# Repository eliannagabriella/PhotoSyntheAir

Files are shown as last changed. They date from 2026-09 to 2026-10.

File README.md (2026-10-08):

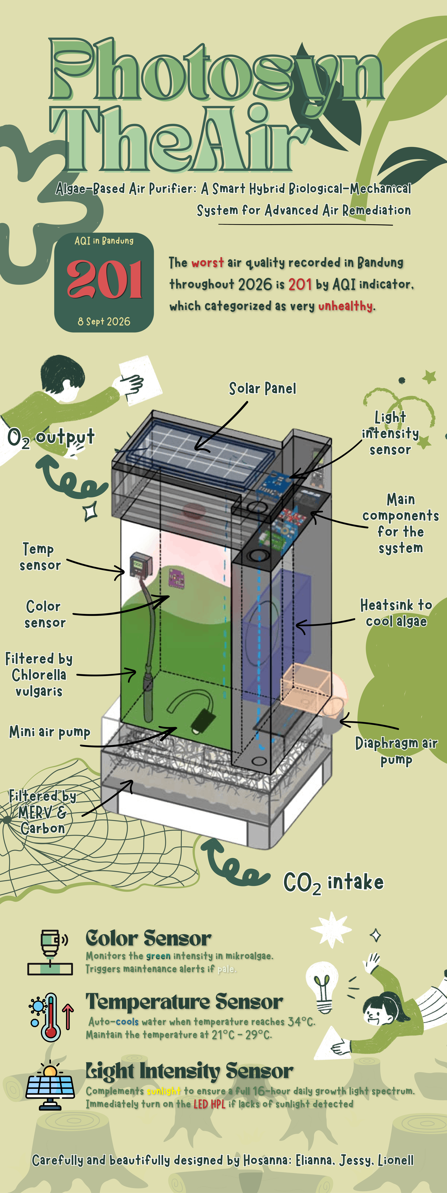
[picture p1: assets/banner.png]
Description of image


# Algae Air Purifier — ESP32-S3 firmware & wiring guide

Air path: MERV filter U25 → activated carbon (1000 iodine) → Ocypus Gamma F12 intake fan → diaphragm pump (micro-bubble diffuser) → algae chamber (mini submersible pump circulates water) → ~27% headspace releases O₂.

The ESP32-S3 doesn't touch the air path, it watches the algae (color, temperature, light) and runs the cooling loop, the grow light, and the dashboard also notifications.

## 1. Bill of materials

| Ref | Part | Where | Why |
|---|---|---|---|
| R1 | 4.7 kΩ resistor | DS18B20 DATA → 3.3V | OneWire is open-drain; without this pull-up the sensor can't pull the line high and reads garbage/-127°C. |
| R2 | 220 Ω resistor | GPIO5 → MOSFET1 gate | Limits inrush current into the gate capacitance; protects the GPIO pin. |
| R3 | 10 kΩ resistor | MOSFET1 gate → GND | Pull-down so the MOSFET is guaranteed OFF while the ESP32 is booting/resetting and the GPIO is floating. Without this, the peltier/fan can glitch on for a moment at every power-up. |
| R4 | 220 Ω resistor | GPIO6 → MOSFET2 gate | Same reason as R2, for the LED MOSFET. |
| R5 | 10 kΩ resistor | MOSFET2 gate → GND | Same reason as R3, for the LED MOSFET (keeps the grow light off during boot). |
| D1 | 1N4007 (or SS34 Schottky) | Across heatsink fan +/- | Flyback diode — the fan is a small inductive DC motor; without a return path for its collapsing field current, every OFF transition puts a voltage spike on MOSFET1's drain. |
| D2, D3, D4 | 1N4007 (optional but recommended) | Across ocypus fan, diaphragm pump, submersible pump | These are wired directly to the rail with no MOSFET, but they're still brushed/BLDC motors — a diode across each protects the 12V rail from switch-on/off spikes when the whole system powers up or a fuse/switch is toggled. |

If your TCS34725 / BH1750 breakout boards are bare chips rather than Adafruit/GY-style modules, also add two 4.7 kΩ pull-ups from SDA and SCL to 3.3V. Almost every breakout board already has these onboard, check before adding a second set, since doubled-up pull-ups just waste a little current, but confirm rather than assume.

## 2. Power architecture

```mermaid
flowchart LR
    SP[Solar panel] --> CH[2S Li-ion charger 4A]
    CH --> BATT[(2x 3.7V battery)]
    BATT --> SU[Step-up XL6019 -> 12V 5A]
    BATT --> SD[Step-down XL4015 -> 3.3V]
    GRID[State Electricity Power / grid, backup] -.-> SU

    SU --> M1[Ocypus F12 fan - always on]
    SU --> M2[Diaphragm pump - always on]
    SU --> M3[Submersible pump - always on]
    SU --> MOS1[MOSFET1 IRLB8721]
    MOS1 --> PEL[Peltier TEC-12706]
    MOS1 --> HSF[Heatsink fan]
    SU --> LM[LM2596S LED driver 12V->5V]
    LM --> MOS2[MOSFET2 IRLB8721 PWM]
    MOS2 --> LED[HPL 3W grow LED]
    LM -.5V.-> ESP[ESP32-S3 VIN]

    SD --> TCS[TCS34725]
    SD --> DS[DS18B20]
    SD --> BH[BH1750]
```

**Priority is physical, not firmware-controlled** : wire the solar panel into the charger's input, the charger's battery output into the XL6019 & XL4015 inputs, and the grid/State Electricity Company supply into the same 12V bus through a diode or manually switched backup input. That priority comes from how you wire the supplies together (e.g. a diode-OR or a physical/automatic transfer switch on the 12V bus) — it isn't something the ESP32-S3 arbitrates in software.

Tie **all grounds together** : battery/12V rail GND, 5V rail GND, 3.3V rail GND, ESP32-S3 GND, and both MOSFET sources. If the ESP32-S3 and the sensors don't share a ground reference with the loads, the MOSFET gate signal has no reliable 0V reference and behaves erratically.

Power the ESP32-S3 board itself from the LM2596S's 5V/3A output (into its `5V`/`VIN` pin), it has plenty of headroom left over for the ~0.6A LED plus the ESP32-S3's ~500mA peak. Don't back power it from the XL4015 3.3V rail unless your specific ESP32-S3 board exposes a raw `3V3` pin meant for external supply (most do; check your board's pinout before relying on it).

## 3. MOSFET1 : Peltier + heatsink fan, ONE MOSFET, wired to switch together

Wire the peltier and the heatsink fan **in parallel**, both between the shared drain node and the 12V rail, so one gate signal switches both:

| From | To |
|---|---|
| 12V rail (+) | Peltier TEC-12706 (+) |
| 12V rail (+) | Heatsink fan (+) |
| Peltier (−) | MOSFET1 Drain |
| Heatsink fan (−) | MOSFET1 Drain |
| D1 cathode (banded end) | 12V rail (+) |
| D1 anode | MOSFET1 Drain |
| MOSFET1 Source | Common GND |
| MOSFET1 Gate | R2 (220 Ω) → ESP32-S3 GPIO5 |
| MOSFET1 Gate | R3 (10 kΩ) → Common GND (pull-down) |

Notes:
- IRLB8721 is a **logic-level** MOSFET (fully on around 4.5V Vgs), so driving it straight from a 3.3V GPIO (through R2) is fine, no gate driver IC needed.
- The peltier alone can pull ~5A; make sure MOSFET1 has a small heatsink if it runs long stretches at that current, and use wire gauge rated for 5A+ on the drain/source path.

## 4. MOSFET2 : Grow LED brightness (PWM)

| From | To |
|---|---|
| LM2596S output (+) | HPL 3W LED (+) |
| HPL 3W LED (−) | MOSFET2 Drain |
| MOSFET2 Source | Common GND |
| MOSFET2 Gate | R4 (220 Ω) → ESP32-S3 GPIO6 |
| MOSFET2 Gate | R5 (10 kΩ) → Common GND (pull-down) |

## 5. Sensors

| Sensor | Pin | ESP32-S3 pin | Notes |
|---|---|---|---|
| TCS34725 | VIN | 3.3V (from XL4015) | |
| | GND | Common GND | |
| | SDA | GPIO8 | shared I2C bus |
| | SCL | GPIO9 | shared I2C bus |
| BH1750 | VCC | 3.3V (from XL4015) | |
| | GND | Common GND | |
| | SDA | GPIO8 | same bus as TCS34725 (different I2C address, no conflict) |
| | SCL | GPIO9 | |
| DS18B20 | VCC (red) | 3.3V (from XL4015) | |
| | GND (black) | Common GND | |
| | DATA (yellow) | GPIO4 | **needs R1, 4.7 kΩ, DATA→3.3V** |

## 6. Always-on motors 

Ocypus Gamma F12 fan, diaphragm pump, and mini submersible pump are wired **straight to the 12V rail** with no ESP32 control.

## 7. Firmware setup

1. Open this folder in VS Code with the PlatformIO extension installed.
2. Edit `include/config.h`:
   - `WIFI_SSID` / `WIFI_PASSWORD`
   - `TELEGRAM_BOT_TOKEN` / `TELEGRAM_CHAT_ID` (see below)
   - Tune `ALGAE_GREEN_RATIO_MIN` / `ALGAE_SATURATION_MIN` / `DAYLIGHT_LUX_THRESHOLD` after a few days of real sensor logging (print raw values to Serial first).
3. **Upload the filesystem first** (PlatformIO sidebar → project tasks → your env → Platform → "Upload Filesystem Image"), so `data/index.html`, `style.css`, `script.js` land on LittleFS.
4. Then build & upload the firmware normally (Upload button / `pio run --target upload`).
5. Open the Serial Monitor at 115200 baud to see the assigned IP address, then browse to `http://<that-ip>/` from any device on the same network for the live dashboard.

### Telegram bot setup (phone notifications)
1. Message **@BotFather** on Telegram → `/newbot` → copy the token into `TELEGRAM_BOT_TOKEN`.
2. Message **@userinfobot** to get your numeric chat ID → put it in `TELEGRAM_CHAT_ID`.
3. Send your new bot any message once (Telegram requires the user to message the bot first before it can message back).
4. Reflash; you'll get a message the first time the algae turns pale, and weekly when nutrients are due.

The website also asks the browser for notification permission and will pop an in-browser notification for the same two events whenever the dashboard tab is open — Telegram is the one that reaches your phone even when the site is closed.

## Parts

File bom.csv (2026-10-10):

Type | Item Name | Qty | Function
ESP32-S3 | ESP32-S3 Microcontroller | 1 | Acts as the main controller, processing sensor data and controlling the system.
DS18B20 | Waterproof temperature sensor | 1 | Measures the temperature of the algae culture.
BH1750 | Sensor intensitas cahaya | 1 | Measures light intensity around the algae chamber.
IRLB8271 | MOSFET | 2 | Switches the power to the pump and other high-current components under ESP32 control.
12V DC | Diaphragm air pump | 1 | Pumps air into the algae chamber to support gas exchange.
F12 BK | Ocypus Gamma Fan Case | 1 | Pulls air through the filtration system.
TCS34725 | Sensor warna | 1 | Measures the algae culture's color to monitor changes in its condition.
 | LED HPL 3 Watt | 1 | Provides light for algae photosynthesis.
2S 4A | Step Up Boost LiPo Charger Module | 1 | Charges the two-cell lithium-ion battery pack.
LM2596S | LED Constant Current Driver 3 Watt | 1 | Regulates the current supplied to the 3 W LED.
XL6019 | Boost Converter 12V 5A | 1 | Increases the battery voltage to supply higher-voltage components.
XL4005 | Buck Converter 3.3V | 1 | Reduces the input voltage to a lower voltage for suitable components.
U25 | MERV FILTER | 1 | Traps dust and other airborne particles.
TEC-12706 | Peltier kit (including heatsink and fan) | 1 | Transfers heat to help control the temperature of the algae chamber.
18650 | Rechargeable Battery 2000mAh | 2 | Store electrical energy for the purifier.
 | Resistor 220Ω | 2 | Limit current in suitable electronic circuits.
 | Resistor 10kΩ | 2 | Act as pull-up or pull-down resistors for stable sensor or MOSFET signals.
136X110-3 | Solar Panel | 1 | Converts sunlight into electrical energy.
1000 Iodine | Activated carbon | 1 | Adsorbs certain gases and volatile organic compounds (VOCs) from the air.

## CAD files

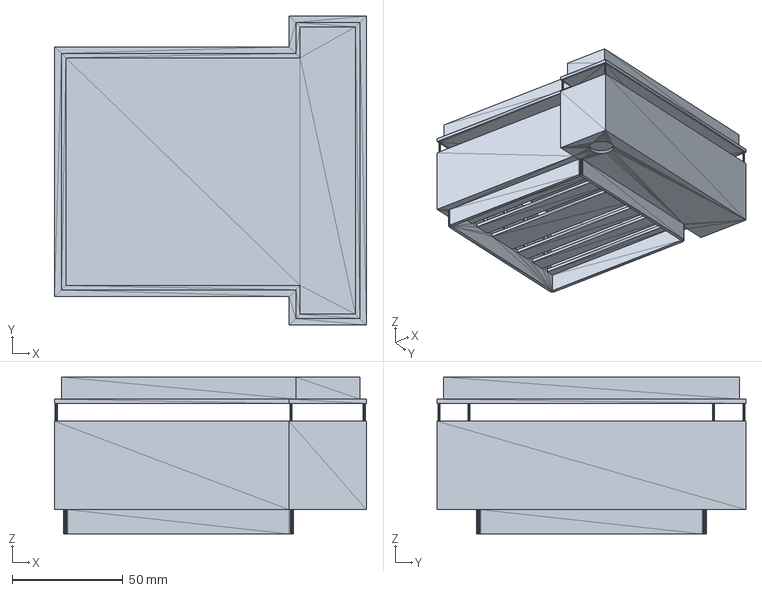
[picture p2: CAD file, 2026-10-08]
cad/layer 4.step
141.2 x 139.8 x 71.0 mm

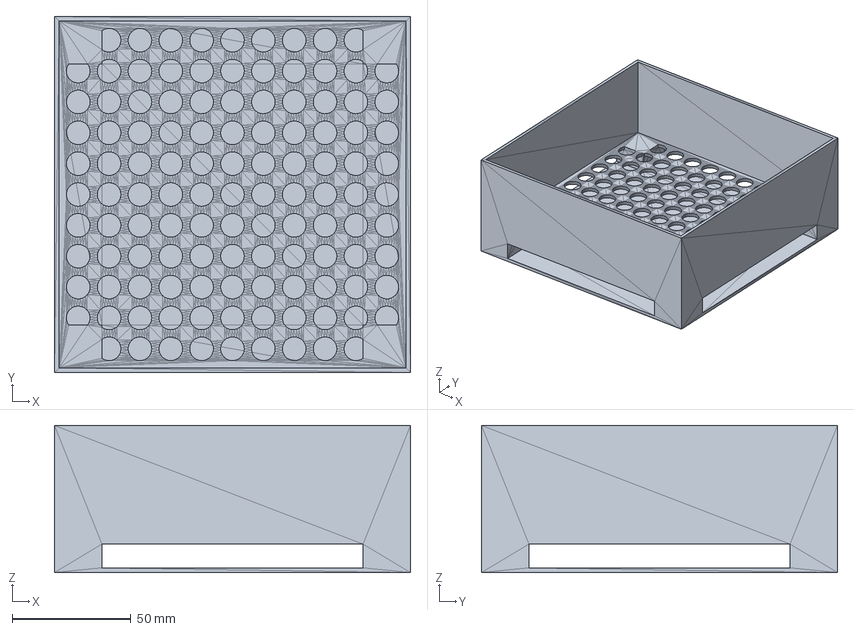
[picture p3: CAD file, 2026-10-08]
cad/Layer 1.step
150.0 x 150.0 x 62.0 mm

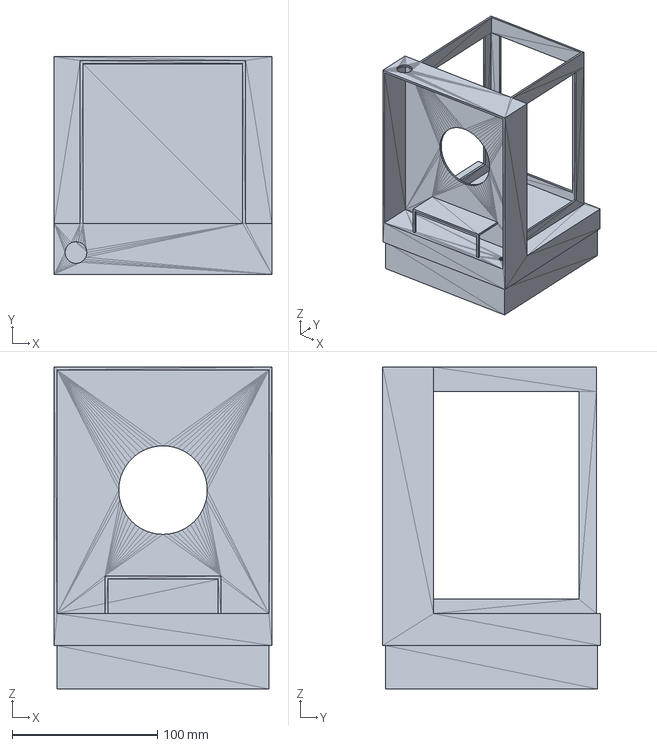
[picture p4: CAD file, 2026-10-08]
cad/layer 2.step
150.0 x 150.0 x 222.0 mm

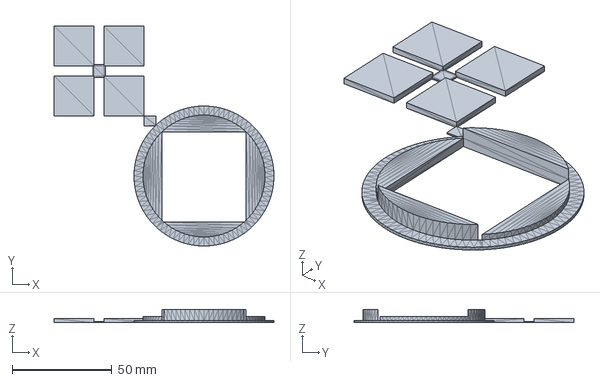
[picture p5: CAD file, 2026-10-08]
cad/mini stuff.step
110.0 x 110.0 x 6.70 mm

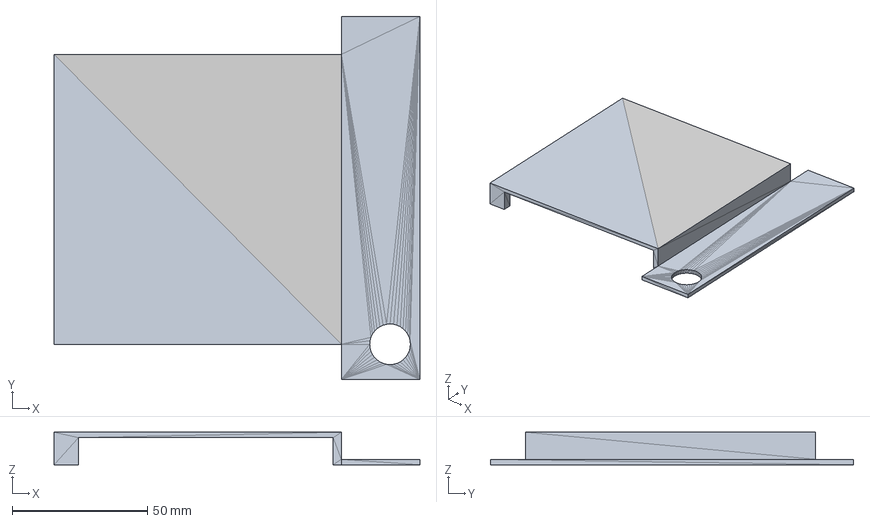
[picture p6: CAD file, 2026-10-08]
cad/Body5.step
135.0 x 134.0 x 12.0 mm

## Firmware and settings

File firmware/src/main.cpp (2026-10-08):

#include <Arduino.h>
#include <WiFi.h>
#include <Wire.h>
#include <time.h>
#include <Preferences.h>
#include <LittleFS.h>
#include <ArduinoJson.h>
#include <ESPAsyncWebServer.h>
#include <AsyncTCP.h>
#include <OneWire.h>
#include <DallasTemperature.h>
#include <BH1750.h>
#include <Adafruit_TCS34725.h>
#include <WiFiClientSecure.h>
#include <HTTPClient.h>
#include "app_config.h"

OneWire oneWire(PIN_ONEWIRE_DATA);
DallasTemperature ds18b20(&oneWire);

BH1750 lightMeter;
Adafruit_TCS34725 tcs = Adafruit_TCS34725(TCS34725_INTEGRATIONTIME_154MS, TCS34725_GAIN_4X);

AsyncWebServer server(80);
AsyncWebSocket ws("/ws");

Preferences prefs;

const int LEDC_CHANNEL_LED = 0;
const int LEDC_FREQ_HZ     = 5000;
const int LEDC_RES_BITS    = 8; // 0-255

struct HistoryPoint {
  uint32_t epoch;
  float temperature;
};
HistoryPoint history[HISTORY_MAX_POINTS];
int historyCount = 0;
int historyHead  = 0; 

struct SystemState {
  float waterTemp        = NAN;
  uint16_t rawR = 0, rawG = 0, rawB = 0, rawC = 0;
  float greenRatio        = 0;
  float saturation        = 0;
  bool  algaeHealthy      = true;
  float lux               = 0;

  bool  coolingOn         = false;   // Peltier + heatsink fan (shared MOSFET)
  bool  ledOn             = false;
  uint8_t ledBrightnessPct = LED_DEFAULT_BRIGHTNESS_PCT;

  double sunlightSeconds  = 0;       // accumulated today
  double ledOnSecondsToday = 0;      // accumulated today
  int    lastResetYday    = -1;      // day-of-year we last reset the counters above

  uint32_t lastNutrientEpoch = 0;
  bool nutrientDue        = false;
  bool wifiConnected      = false;
  bool timeSynced         = false;
} state;

unsigned long lastLoopMs    = 0;
unsigned long lastHistoryMs = 0;
bool wasHealthyLastCheck    = true;

//Prototypes
void connectWiFi();
void syncTime();
void setupSensors();
void setupWebServer();
void readSensors(float dtSeconds);
void controlCooling();
void controlGrowLight(float dtSeconds);
void maybeResetDailyCounters();
void maybeCheckNutrientReminder();
void pushHistoryPoint();
void broadcastState();
void sendTelegramMessage(const String &text);
String buildStateJson();
String buildHistoryJson();
void onWsEvent(AsyncWebSocket *server, AsyncWebSocketClient *client,
               AwsEventType type, void *arg, uint8_t *data, size_t len);


void setup() {
  Serial.begin(115200);
  delay(300);
  Serial.println("\n[algae] booting...");

  pinMode(PIN_STATUS_LED, OUTPUT);
  pinMode(PIN_MOSFET_COOLING, OUTPUT);
  digitalWrite(PIN_MOSFET_COOLING, LOW); // fail-safe: cooling OFF until first read

  ledcSetup(LEDC_CHANNEL_LED, LEDC_FREQ_HZ, LEDC_RES_BITS);
  ledcAttachPin(PIN_MOSFET_LED, LEDC_CHANNEL_LED);
  ledcWrite(LEDC_CHANNEL_LED, 0); // LED off until first control pass



  Wire.begin(PIN_I2C_SDA, PIN_I2C_SCL);
  
  setupSensors();

  if (!LittleFS.begin(true)) {
    Serial.println("[algae] LittleFS mount failed! (did you run 'Upload Filesystem Image'?)");
  }

  connectWiFi();
  syncTime();
  setupWebServer();

  lastLoopMs = millis();
  lastHistoryMs = millis();
  Serial.println("[algae] ready.");
}

void loop() {
  ws.cleanupClients();

  unsigned long now = millis();
  if (now - lastLoopMs >= LOOP_INTERVAL_MS) {
    float dt = (now - lastLoopMs) / 1000.0f;
    lastLoopMs = now;

    state.wifiConnected = (WiFi.status() == WL_CONNECTED);
    digitalWrite(PIN_STATUS_LED, (millis() / 500) % 2);

    readSensors(dt);
    maybeResetDailyCounters();
    controlCooling();
    controlGrowLight(dt);
    maybeCheckNutrientReminder();
    broadcastState();
  }

  if (now - lastHistoryMs >= HISTORY_SAMPLE_MS) {
    lastHistoryMs = now;
    pushHistoryPoint();
  }
}

//WiFi
void connectWiFi() {
  WiFi.mode(WIFI_STA);
  WiFi.begin(WIFI_SSID, WIFI_PASSWORD);
  Serial.print("[algae] connecting to WiFi");
  unsigned long start = millis();
  while (WiFi.status() != WL_CONNECTED && millis() - start < 20000) {
    delay(300);
    Serial.print(".");
  }
  Serial.println();
  if (WiFi.status() == WL_CONNECTED) {
    Serial.printf("[algae] WiFi connected, IP = %s\n", WiFi.localIP().toString().c_str());
    state.wifiConnected = true;
  } else {
    Serial.println("[algae] WiFi NOT connected — dashboard/telegram will retry in background.");
  }
}

void syncTime() {
  configTime(GMT_OFFSET_SEC, DAYLIGHT_OFFSET_SEC, NTP_SERVER_1, NTP_SERVER_2);
  struct tm timeinfo;
  if (getLocalTime(&timeinfo, 8000)) {
    state.timeSynced = true;
    Serial.println(&timeinfo, "[algae] time synced: %Y-%m-%d %H:%M:%S");
  } else {
    Serial.println("[algae] NTP sync failed — will retry silently; daily/weekly timers use millis() fallback.");
  }
}

//Sensors
void setupSensors() {
  ds18b20.begin();
  ds18b20.setWaitForConversion(true);

  if (!lightMeter.begin(BH1750::CONTINUOUS_HIGH_RES_MODE)) {
    Serial.println("[algae] BH1750 not found — check wiring/address.");
  }

  if (!tcs.begin()) {
    Serial.println("[algae] TCS34725 not found — check wiring/address.");
  }
}

void readSensors(float dtSeconds) {
  //Temperature
  ds18b20.requestTemperatures();
  float t = ds18b20.getTempCByIndex(0);
  if (t > -100 && t < 125) { // DEVICE_DISCONNECTED_C guard
    state.waterTemp = t;
  }

  //Algae health by color
  uint16_t r, g, b, c;
  tcs.getRawData(&r, &g, &b, &c);
  state.rawR = r; state.rawG = g; state.rawB = b; state.rawC = c;

  float total = (float)r + g + b;
  if (total > 0) {
    state.greenRatio = g / total;
    uint16_t mx = max(r, max(g, b));
    uint16_t mn = min(r, min(g, b));
    state.saturation = (mx > 0) ? (float)(mx - mn) / mx : 0;
  }
  bool healthyNow = (state.greenRatio >= ALGAE_GREEN_RATIO_MIN) &&
                     (state.saturation >= ALGAE_SATURATION_MIN);
  state.algaeHealthy = healthyNow;

  if (wasHealthyLastCheck && !healthyNow) {
    // just turned unhealthy -> notify once on the transition
    sendTelegramMessage(
      "\xE2\x9A\xA0\xEF\xB8\x8F Algae Air Purifier: algae color looks PALE. "
      "Health check needed (green ratio " + String(state.greenRatio, 2) +
      ", saturation " + String(state.saturation, 2) + ")."
    );
  }
  wasHealthyLastCheck = healthyNow;

  // --- Light ---
  float l = lightMeter.readLightLevel();
  if (l >= 0) state.lux = l;
}

//Cooling control
void controlCooling() {
  if (isnan(state.waterTemp)) return; // don't act on a bad reading

  if (!state.coolingOn && state.waterTemp >= TEMP_COOL_ON_C) {
    state.coolingOn = true;
  } else if (state.coolingOn && state.waterTemp <= TEMP_COOL_OFF_C) {
    state.coolingOn = false;
  }
  // MOSFET #1 switches Peltier TEC-12706 and the heatsink fan TOGETHER — see wiring guide.
  digitalWrite(PIN_MOSFET_COOLING, state.coolingOn ? HIGH : LOW);
}

//Light control
void controlGrowLight(float dtSeconds) {
  bool isDaylight = state.lux >= DAYLIGHT_LUX_THRESHOLD;

  if (isDaylight) {
    state.sunlightSeconds += dtSeconds;
  }

  double requiredSeconds = (TARGET_LIGHT_HOURS * 3600.0) - state.sunlightSeconds;
  if (requiredSeconds < 0) requiredSeconds = 0;

  bool needMoreLightToday = state.ledOnSecondsToday < requiredSeconds;
  bool ledShouldBeOn = (!isDaylight) && needMoreLightToday;

  if (ledShouldBeOn) {
    state.ledOnSecondsToday += dtSeconds;
  }
  state.ledOn = ledShouldBeOn;

  uint8_t duty = ledShouldBeOn ? map(state.ledBrightnessPct, 0, 100, 0, 255) : 0;
  ledcWrite(LEDC_CHANNEL_LED, duty);
}

void maybeResetDailyCounters() {
  struct tm timeinfo;
  if (!getLocalTime(&timeinfo, 5)) return; // no time yet, skip (keeps accumulating, harmless)

  if (state.lastResetYday != timeinfo.tm_yday) {
    state.lastResetYday = timeinfo.tm_yday;
    state.sunlightSeconds = 0;
    state.ledOnSecondsToday = 0;
    Serial.println("[algae] new day -> sunlight/LED counters reset");
  }
}

//Nutrient reminder
void maybeCheckNutrientReminder() {
  struct tm timeinfo;
  if (!getLocalTime(&timeinfo, 5)) return;

  time_t nowEpoch;
  time(&nowEpoch);

  if (state.lastNutrientEpoch == 0) {
    // first boot ever — start the countdown from now instead of alerting immediately
    state.lastNutrientEpoch = (uint32_t)nowEpoch;
    prefs.putUInt("lastNutrient", state.lastNutrientEpoch);
    return;
  }

  double daysSince = difftime(nowEpoch, state.lastNutrientEpoch) / 86400.0;
  bool due = daysSince >= NUTRIENT_INTERVAL_DAYS;

  if (due && !state.nutrientDue) {
    sendTelegramMessage(
      "\xF0\x9F\x8C\xBF Algae Air Purifier: it's been " + String((int)daysSince) +
      " days — time to add nutrients to the algae chamber."
    );
  }
  state.nutrientDue = due;
}

//History
void pushHistoryPoint() {
  time_t nowEpoch;
  time(&nowEpoch);
  history[historyHead].epoch = (uint32_t)nowEpoch;
  history[historyHead].temperature = state.waterTemp;
  historyHead = (historyHead + 1) % HISTORY_MAX_POINTS;
  if (historyCount < HISTORY_MAX_POINTS) historyCount++;
}

String buildHistoryJson() {
  JsonDocument doc;
  JsonArray arr = doc.to<JsonArray>();
  int startIdx = (historyCount < HISTORY_MAX_POINTS) ? 0 : historyHead;
  for (int i = 0; i < historyCount; i++) {
    int idx = (startIdx + i) % HISTORY_MAX_POINTS;
    JsonObject o = arr.add<JsonObject>();
    o["t"] = history[idx].epoch;
    if (isnan(history[idx].temperature)) {
      o["temp"] = nullptr;
    } else {
      o["temp"] = history[idx].temperature;
    }
  }
  String out;
  serializeJson(doc, out);
  return out;
}

//Telegram
void sendTelegramMessage(const String &text) {
  if (!TELEGRAM_ENABLED) return;
  if (WiFi.status() != WL_CONNECTED) return;

  WiFiClientSecure client;
  client.setInsecure(); // Telegram's cert chain rotates; skip pinning for simplicity
  HTTPClient https;

  String url = "https://api.telegram.org/bot" + String(TELEGRAM_BOT_TOKEN) +
               "/sendMessage?chat_id=" + String(TELEGRAM_CHAT_ID) +
               "&text=" + text;
  // Minimal URL-encoding for spaces; good enough for our own ASCII alert strings.
  url.replace(" ", "%20");
  

  if (https.begin(client, url)) {
    int code = https.GET();
    Serial.printf("[algae] telegram sendMessage -> HTTP %d\n", code);
    https.end();
  } else {
    Serial.println("[algae] telegram: could not begin HTTPS connection");
  }
}

//Web/State
String buildStateJson() {
  JsonDocument doc;
  if (isnan(state.waterTemp)) {
    doc["waterTemp"] = nullptr;
  } else {
    doc["waterTemp"] = state.waterTemp;
  }
  doc["greenRatio"]      = state.greenRatio;
  doc["saturation"]      = state.saturation;
  doc["algaeHealthy"]    = state.algaeHealthy;
  doc["lux"]             = state.lux;

  doc["coolingOn"]       = state.coolingOn;     // Peltier + heatsink fan
  doc["ledOn"]           = state.ledOn;
  doc["ledBrightnessPct"]= state.ledBrightnessPct;

  doc["sunlightHoursToday"] = state.sunlightSeconds / 3600.0;
  doc["ledHoursToday"]      = state.ledOnSecondsToday / 3600.0;
  doc["targetLightHours"]   = TARGET_LIGHT_HOURS;

  doc["nutrientDue"]        = state.nutrientDue;
  doc["lastNutrientEpoch"]  = state.lastNutrientEpoch;
  doc["nutrientIntervalDays"] = NUTRIENT_INTERVAL_DAYS;

  doc["wifiConnected"]     = state.wifiConnected;
  doc["timeSynced"]        = state.timeSynced;

  time_t nowEpoch; time(&nowEpoch);
  doc["nowEpoch"] = (uint32_t)nowEpoch;

  String out;
  serializeJson(doc, out);
  return out;
}

void broadcastState() {
  if (ws.count() > 0) {
    ws.textAll(buildStateJson());
  }
}

void onWsEvent(AsyncWebSocket *server, AsyncWebSocketClient *client,
               AwsEventType type, void *arg, uint8_t *data, size_t len) {
  if (type == WS_EVT_CONNECT) {
    client->text(buildStateJson());
  }
}

void setupWebServer() {
  ws.onEvent(onWsEvent);
  server.addHandler(&ws);

  server.serveStatic("/", LittleFS, "/").setDefaultFile("index.html");

  server.on("/api/state", HTTP_GET, [](AsyncWebServerRequest *request) {
    request->send(200, "application/json", buildStateJson());
  });

  server.on("/api/history", HTTP_GET, [](AsyncWebServerRequest *request) {
    request->send(200, "application/json", buildHistoryJson());
  });

  server.on("/api/nutrient/reset", HTTP_POST, [](AsyncWebServerRequest *request) {
    time_t nowEpoch; time(&nowEpoch);
    state.lastNutrientEpoch = (uint32_t)nowEpoch;
    state.nutrientDue = false;
    prefs.putUInt("lastNutrient", state.lastNutrientEpoch);
    request->send(200, "application/json", "{\"ok\":true}");
  });

  server.on("/api/led", HTTP_POST, [](AsyncWebServerRequest *request) {
    if (request->hasParam("percent", true)) {
      int pct = request->getParam("percent", true)->value().toInt();
      pct = constrain(pct, 0, 100);
      state.ledBrightnessPct = pct;
      prefs.putUChar("ledPct", pct);
      request->send(200, "application/json", "{\"ok\":true}");
    } else {
      request->send(400, "application/json", "{\"ok\":false,\"error\":\"missing percent\"}");
    }
  });

  server.begin();
  Serial.println("[algae] web server started on port 80");
}

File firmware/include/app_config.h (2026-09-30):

#pragma once
// ============================================================================
//  config.h — every value you are likely to want to change lives here.
// ============================================================================
// ---------------------------------------------------------------- WiFi -----
#define WIFI_SSID       "moon"
#define WIFI_PASSWORD   "kosongtujuh"

// ------------------------------------------------------------ Telegram ----
// Phone notifications are sent through a Telegram bot (works even if nobody
// has the website open). Create a bot with @BotFather, then message
// @userinfobot to get your numeric chat id.
#define TELEGRAM_ENABLED     true
#define TELEGRAM_BOT_TOKEN   "8929898243:AAE_l4kxrwc-241SJGGp3-cykEQA1mvfgDc"
#define TELEGRAM_CHAT_ID     "6801556690"

// ------------------------------------------------------------- Time -------
// Bandung, Indonesia = UTC+7, no DST.
#define GMT_OFFSET_SEC       (7 * 3600)
#define DAYLIGHT_OFFSET_SEC  0
#define NTP_SERVER_1         "pool.ntp.org"
#define NTP_SERVER_2         "time.nist.gov"

// -------------------------------------------------------------- Pins ------
// I2C bus (TCS34725 color sensor + BH1750 light sensor)
#define PIN_I2C_SDA          8
#define PIN_I2C_SCL          9

// DS18B20 waterproof temperature probe (OneWire)
#define PIN_ONEWIRE_DATA     4      // needs a 4.7k pull-up to 3.3V, see wiring guide

// MOSFET #1 (IRLB8721) — switches Peltier TEC-12706 + heatsink fan TOGETHER
#define PIN_MOSFET_COOLING   5      // digital ON/OFF only

// MOSFET #2 (IRLB8721) — switches / PWM-dims the HPL 3W grow LED
#define PIN_MOSFET_LED       6      // PWM (LEDC)

// Onboard status LED (optional, purely for a heartbeat blink)
#define PIN_STATUS_LED       2

// ---------------------------------------------------- Control thresholds --
// Temperature (°C) hysteresis for the Peltier cooling loop
#define TEMP_COOL_ON_C        35.0f
#define TEMP_COOL_OFF_C       30.0f

// Lux level above which we consider the algae to be getting "real" sunlight.
// Direct sun is 30,000-100,000 lux, open shade / bright overcast is
// 1,000-10,000 lux. Start at 2000 and tune with your own BH1750 readings
// logged over a few days.
#define DAYLIGHT_LUX_THRESHOLD   2000.0f

// Target total hours of light (natural + grow LED) per day
#define TARGET_LIGHT_HOURS       16.0f

// Grow LED brightness when it IS on, as a duty-cycle percentage (0-100).
// Adjustable at runtime from the website too.
#define LED_DEFAULT_BRIGHTNESS_PCT   80

// Algae health heuristic (TCS34725). These are STARTING POINTS — print
// gRatio/saturation to Serial with a known-fresh sample and a known-pale
// sample, then tighten these numbers for your specific algae/water/chamber.
#define ALGAE_GREEN_RATIO_MIN     0.38f   // g / (r+g+b)
#define ALGAE_SATURATION_MIN      0.15f   // (max-min)/max of r,g,b

// Nutrient dosing reminder interval
#define NUTRIENT_INTERVAL_DAYS    7

// Sensor loop / broadcast period
#define LOOP_INTERVAL_MS          2000UL
// How often a temperature point is pushed onto the history buffer for the graph
#define HISTORY_SAMPLE_MS         30000UL
#define HISTORY_MAX_POINTS        200

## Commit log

2026-10-06 Refine README for clarity and consistency
    Updated various sections for clarity and consistency, including air path details, bill of materials, power architecture, and firmware setup instructions.
2026-10-08 Create cad
2026-10-08 redirecting and adding additional files
    [Body5.step, Layer 1.step, bom.csv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]
2026-10-10 adding bom
    [bom.csv]
2026-10-14 revising bom
2026-10-24 adding pcb
2026-10-25 Adding fan, peltier, and solar panel to the schematic
2026-10-27 Added recent fixed schematics and pcb
